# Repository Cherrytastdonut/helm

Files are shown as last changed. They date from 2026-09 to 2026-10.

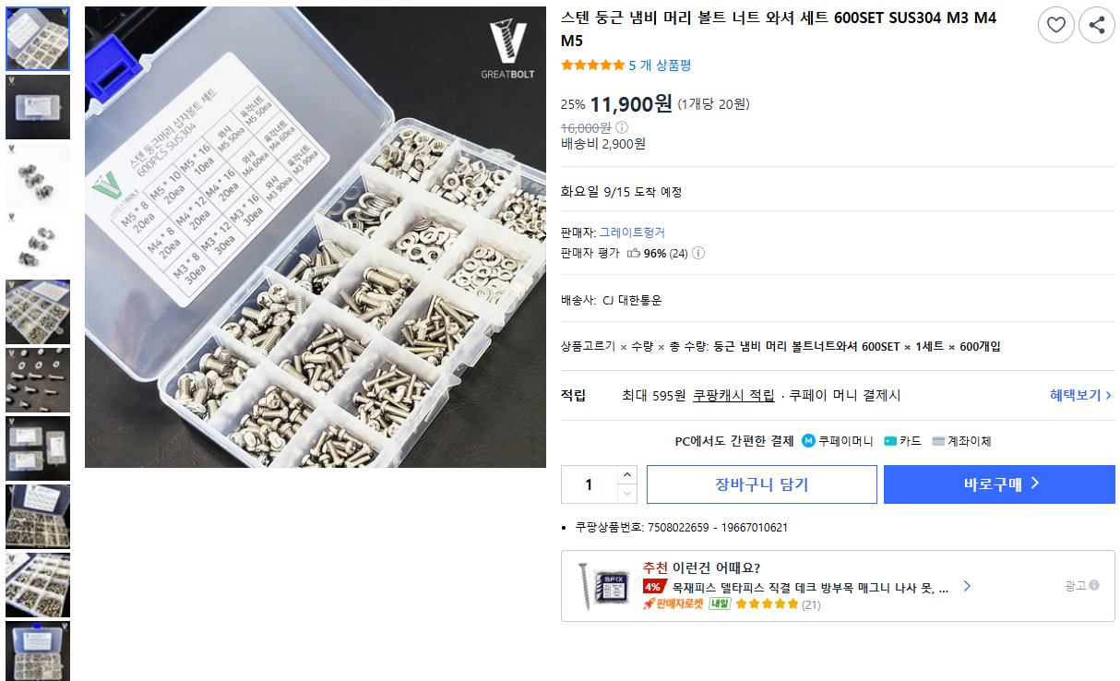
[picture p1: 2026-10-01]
assets/purchase-evidence/fastener-kit.png

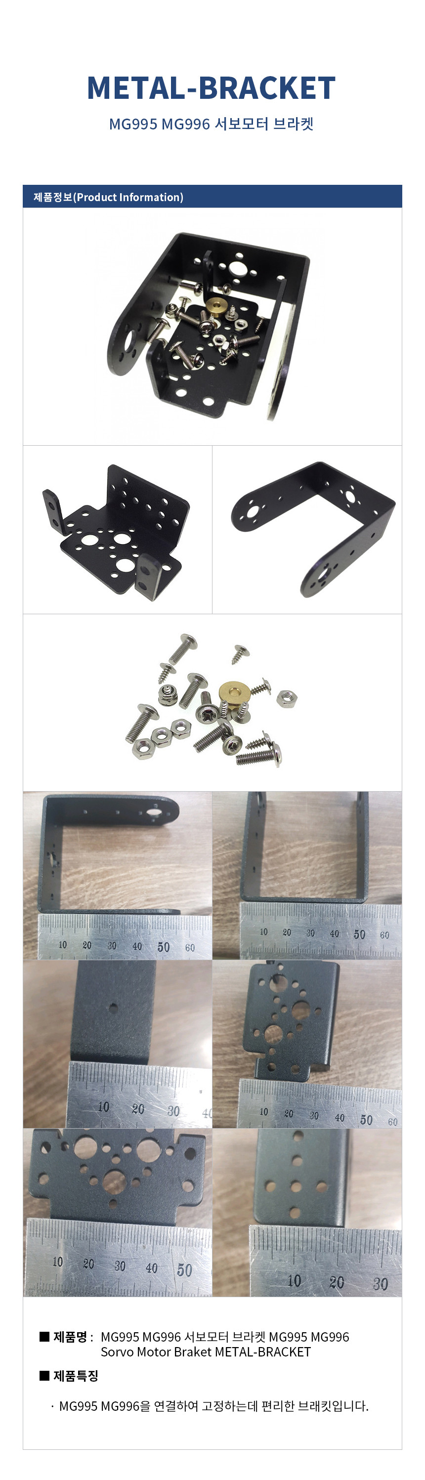
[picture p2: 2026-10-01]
assets/purchase-evidence/mg995-detail.jpg

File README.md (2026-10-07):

# HELM 자율점검 로봇

**최신: MEASURED_LAYOUT_20261006 · 3,888개 노드 · 재단·통전 승인 전 검토본입니다.** 구매 93개 항목, 치수표 13개 기록, CAD 노드를 연결하고 26개 형상에 치수와 배치를 반영했습니다.

1. [현재 상태](docs/00-status.md)와 [부품번호·실측 적용표](data/measurements-20261006/HELM_부품번호_실측적용표.xlsx).
2. [실측 반영·제작 가이드 6쪽](drawings/measurements-20261006/HELM_MEASURED_BUILD_GUIDE_KO.pdf).
3. [A3 1:1 윤곽 검토도 20쪽](drawings/measurements-20261006/HELM_CURRENT_FLAT_PROFILES_REVIEW_A3.pdf)와 [섀시 기준 4홀 대조 양식](drawings/measurements-20261006/HELM_CHASSIS_4HOLE_CHECK_A3.pdf).
4. [전체 CAD 백업 복원](docs/11-artifacts.md)과 [필수 확인·현장 조정](docs/15-needed-measurements.md).

| 자료 | 바로가기 |
|---|---|
| 모든 구매 항목 | [93개 번호 CSV](data/measurements-20261006/parts-numbered.csv) · [치수 원문과 적용](data/measurements-20261006/measurement-register.csv) |
| 최신 CAD·설계 범위 | [이번 반영 내용](docs/16-measured-layout.md) · [재생성 코드](cad/measurements-20261006/source/) |
| 제작 준비 | [재단](docs/04-fabrication.md) · [조립](docs/05-assembly.md) · [전기](docs/06-electrical.md) |
| 검사와 미확정 사항 | [검증 범위](docs/08-validation.md) · [겹침 24쌍·회전 10쌍](docs/10-open-items.md) |
| 기존 근거 | [상품 사진 대조](docs/14-product-photo-review.md) · [1차 구매](docs/parts/first-purchase.md) · [2차 구매](docs/parts/second-purchase.md) |
| 이전 작업 | [아카이브](archives/README.md) · [이력](docs/09-history.md) · [FlutterFlow 초안](docs/13-flutterflow-ai.md) |

보유 판재는 **5T 포맥스 600×900 mm 2장**입니다. 작은 칩 개별 측정은 필요하지 않으며, 고정 부품의 홀·배선·스페이서는 현장에서 조정합니다. 혼·기준 홀·큰 장착 홀·범퍼 기능은 먼저 확인해야 합니다. 2차 구매품을 모두 설치할 필요는 없습니다.

`LIB_SER0063.zip`은 모터 몸체 CAD입니다. 혼은 별도입니다. 형상 생략은 체결 완료나 간섭 해결을 뜻하지 않습니다. 과거 FINAL/PASS 또는 디자인·검색 불필요는 당시 확인한 본체와 검사 범위에 한정하며 최신 [상태 JSON](data/project-status.json)을 우선합니다.

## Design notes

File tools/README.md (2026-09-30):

# 자료 확인 도구

두 도구는 Python 3.9 이상과 표준 라이브러리만 사용합니다. 저장소 루트에서 실행합니다.

```bash
python tools/check_repository.py
python tools/restore_archives.py --all --verify-only
python tools/restore_archives.py --all --extract
```

첫 명령은 문서 링크·파일 수·상태 범위·파일 해시 목록을 검사합니다. 두 번째는 출력 파일을 만들지 않고 ZIP 조각과 전체 원본의 SHA-256을 검사합니다. 마지막은 검사가 끝난 ZIP을 downloads에 복원하고 각 원본별 빈 폴더에 풉니다.

의도한 문서 변경 후 `python tools/check_repository.py --write-catalog`로 파일 목록을 갱신하고 변경 내용을 검토하세요. 이 검사는 CAD 간섭 검증이나 실물 제작 승인이 아닙니다.

[원본 복원 안내](../docs/11-artifacts.md) · [CAD 생성 코드와 실행 이력](../docs/12-reproduce.md)

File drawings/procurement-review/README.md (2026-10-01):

# 현재 검토용 도면

[변경 안내 6쪽](HELM_PROCUREMENT_CHANGE_GUIDE_KO.pdf) · [A3 윤곽 20쪽](HELM_CURRENT_FLAT_PROFILES_REVIEW_A3.pdf)

A3 윤곽은 1:1 종이 대조용입니다. 실제 크기 100%로 인쇄하고 100 mm 기준선을 확인합니다. 최종 재단 승인본이 아닙니다. 1.6 mm 분배기판은 포맥스 대상이 아니며 깊이 형상은 STEP으로 확인합니다. [페이지 출처](../../data/procurement-review/DRAWING_INDEX.json).

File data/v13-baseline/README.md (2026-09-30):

# 자료 안내

과거 BOM·체결·배선·홀·목차입니다. 현재 구매 재고나 최신 배선 확정표가 아닙니다.

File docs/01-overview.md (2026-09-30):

# 전체 구성

기존 도면에서 HELM은 Autonomous Inspection Robot으로 정의된 궤도형 점검 로봇입니다. 아래는 확보된 기구·구매 구성이며 실제 운용 성능 검증 결과가 아닙니다.

| 계통 | 주요 장치 | 역할 |
|---|---|---|
| 이동 | Hiwonder 궤도 섀시·엔코더 모터, MDD10A | 주행 구동 |
| 연산 | Jetson Orin Nano Super 8GB, SSD, AX210 | 연산·저장·통신 |
| 제어 | ESP32 DevKit 38핀 | 저수준 인터페이스 후보, 펌웨어 미확보 |
| 감지 | C920, MLX90640 계열, RPLIDAR A2M12, BNO085 | 영상·열·거리·자세 |
| 카메라 구동 | SER0063 ×2 | 팬·틸트, 혼 미확정 |
| 전원/보호 | AGM 12V 7Ah, 변환기, 배전·퓨즈·릴레이·E-STOP | 실제 결선/정격 확인 필요 |
| 접촉/출력 | 4개 리미트 스위치, USB 스피커 | 범퍼 감지·경보 구성 |

```mermaid
flowchart TD
    A[영상·거리·열 입력] --> B[Jetson 연산부]
    B --> C[ESP32 제어부]
    D[엔코더·범퍼·자세 입력] --> C
    C --> E[주행 드라이버]
    C --> F[카메라 서보]
    B --> G[로그·상태·경보]
```

기능 관계도입니다. 확정 배선도나 GPIO 핀맵으로 사용하지 않습니다. 기구는 하부 프레임, 배터리/전원부, 상부 데크, 제어부, LiDAR 타워, 카메라, 범퍼로 구성됩니다.

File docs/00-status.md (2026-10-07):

# 현재 상태

**MEASURED_LAYOUT_20261006 / 3,888개 노드 / 재단·통전 승인 전**입니다.

| 항목 | 현재 내용 |
|---|---|
| 부품 매핑 | 1차 29 + 2차 64 = 93행, CAD 노드 3,888개 연결 |
| 치수 기록 | 13개 중 실측·근사 실측 10개. 상품명·카탈로그 표기를 별도 분류 |
| 형상 변경 | 꺽쇠 16개, C920 7개, 패드·측판·로커 = 26개 |
| 제외한 형상 | 미구매 ADC 몸체 27개, 구형 꺽쇠 체결 형상 160개, 스트랩 2개, 배선 1개 |
| 유지한 몸체 | CP003·배터리·승압기·퓨즈박스·SER0063·C715·열화상 |
| 산출물 | 제작 후보 STEP 128개, DXF 20개, 가이드 6쪽, A3 윤곽 20쪽, 섀시 4홀 확인지 |

변경부 후보 80쌍 중 겹침 24쌍(C920 내부 참조 4쌍 포함), 카메라 9개 자세 검사에서 고유 10쌍을 기록했습니다. 체결품 생략은 간섭 해결이나 체결 완료가 아닙니다. 팬 ±45°·틸트 ±20°는 검사 자세이며 승인 동작 범위가 아닙니다.

[필수 확인](15-needed-measurements.md)은 혼·비상정지·섀시 기준 홀·범퍼입니다. 고정 꺽쇠·CP003 홀은 실물 전사, 스페이서·배선은 현장 조정합니다. 모터 본체나 작은 칩을 다시 전부 재지 않습니다. MG995 프레임은 회전축·하중 부품으로 채택할 때만 내측·홀·두께가 필요합니다.

[부품번호·실측 적용표](../data/measurements-20261006/HELM_부품번호_실측적용표.xlsx) · [CAD 복원](11-artifacts.md) · [검사 상세](08-validation.md)

최신 같은 리비전의 CAD·치수표·검증이 우선입니다. 과거 FINAL/PASS나 디자인·검색 불필요는 당시 확인한 본체와 범위에 한정합니다.

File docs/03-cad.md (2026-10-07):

# CAD·설계도 읽는 법

현재 **MEASURED_LAYOUT_20261006**은 3,888개 노드의 실측 반영 검토본입니다. [상세 변경](16-measured-layout.md)과 [현재 CAD 복원](11-artifacts.md)을 먼저 확인해 주세요.

| 파일 | 사용 범위 |
|---|---|
| 전체 STEP | 전체 조립체 배치. mm 단위 |
| EDITABLE/HELM_WORK | 현재 BREP 3,888개와 관계 메타데이터. 원 제조사 전체 피처 이력은 아님 |
| 제작 STEP 128개 | 전체 좌표를 유지한 3D 홈·깊이. 모두 포맥스 재단품은 아님 |
| 변경 STEP 26개 | 꺽쇠·카메라·패드·측판·로커. 제작 후보와 일부 중복 |
| 선택 재고 STEP 3개 | 부스바·MG995 두 프레임의 외접 상자. 미설치, 상세 제조 CAD 아님 |
| DXF 20개 | 일정 두께 관통 윤곽. 19개 5T + 1개 1.6T 분배기판 참조 |
| A3 윤곽 20쪽 | 실제 크기 100%, 페이지 맞춤 해제 후 100 mm 선 확인 |
| 섀시 4홀 확인지 | 실물에 대조하는 중심점. 본판 재단 도면 아님 |

꺽쇠의 실제 홀·두께·리브, C920 힌지 상대 자세, 로커 내부 깊이 분할, 혼 연결부는 미확정입니다. 고정 부품 홀은 실물을 놓고 전사합니다. 깊이가 다른 형상을 평판으로 납작하게 가공하지 않습니다.

과거 V13(4,102개), SER0063(4,152개), PROCUREMENT(4,078개) 파일은 이력입니다. 현재 파일을 덮어쓰거나 과거 변경 스크립트를 반복 적용하지 않습니다.

[현재 변경 기록](../data/measurements-20261006/REVISION.json) · [STEP·DXF 인덱스](../data/measurements-20261006/FABRICATION_INDEX.json)

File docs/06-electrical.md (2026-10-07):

> 현재 치수 반영 CAD는 MEASURED_LAYOUT_20261006입니다. 이 문서의 전기 검토는 배선 실물 시험 완료를 뜻하지 않습니다. CAD의 무효 경로는 [현재 기록](../data/measurements-20261006/wires.json)을 따릅니다.

# 배선·전원 준비

CAD의 배선 의도와 미해결 항목입니다. 완성된 결선도나 확정 핀맵이 아닙니다.

12V AGM 배터리, 메인 퓨즈/스위치, 분기 보호·배전, 모터 차단 릴레이/E-STOP, 연산용 승압부, 5V 보조 전원부가 구매·CAD 자료에 있습니다. 실제 연결·정격은 부품 자료와 실측으로 확인합니다.

| 항목 | 현재 문제 | 완료 조건 |
|---|---|---|
| SER0063 2개 | 구형 4.8V 메모 사용 불가 | 제조사 5-8.4V 범위, 공급 전압·공유 부하·동시 전류 확인 |
| 서보 2개 배선 | 이전 경로 제거 | 실제 리드선 출구·극성·신호 리턴·움직임 루프 |
| C920 USB | 높이 변경 뒤 경로 제거 | 팬/틸트 움직임·굽힘·고정·플러그 접근 |
| RPLIDAR | 기존 배선표에 경로 없음 | 실제 케이블·Jetson 인터페이스·스캔 영역 밖 경로 |
| ADS1115 | 구매 목록에 없어 받침·체결품·가짜 연결 제거 | 보유 부품 기준 전압 취득 회로 확정 |
| 전압 분압 입력 | 보조 퓨즈 요구가 형상에 직렬 반영되지 않음 | 보유 보호부품·정격·연결 반영 |
| 배전 | CP003 외곽 적용, 기존 BUS 포트 좌표/경로 무효 | 단자 방향·정격·기구 위치·분기 식별 |
| 릴레이/E-STOP/퓨즈 | 실물 동작 미검증 | 접점·코일·억제소자 방향·선재·정격·차단 확인 |
| 커넥터 | 외형·접근 방향 참조 | 실제 키·공동·엔코더/모터 핀·극성 확인 |

SER0063 제조사 출처: https://www.dfrobot.com/product-2787.html (2026-09-30 확인). CAD 모양으로 핀 번호를 추정하지 않습니다.

[wires.json](../data/procurement-review/wires.json)의 앞선 SER0063 수정에 따른 세 경로는 NOT_RELEASED_SER0063_REPLACEMENT입니다. [ports.json](../data/procurement-review/ports.json)의 새 서보 리드선은 UNMEASURED_LEAD_EXIT입니다. 다른 기존 경로도 전체 실물 검증을 새로 완료한 것이 아닙니다.

과거 [배선표](../data/v13-baseline/WIRING_TABLE.csv)와 PDF 183쪽 E-211은 문제 추적용입니다. 단자 식별 → 전원 분리 상태 배선/단락 확인 → 부하 연결 전 출력 전압/극성 확인 → 회로별 단계 확인 → 차단/비상정지 → 가동부 케이블 확인을 기록합니다.

## 구매품 반영에 따른 현재 배선 상태

이번 리비전에서 배전 15개, 열화상 1개, ADC/전압취득 2개, 총 18개 경로를 무효 처리했습니다. geometry_valid=false, points=[], 길이 미확정이며 앞선 서보 2개·C920 경로 보류도 유지합니다. [이전 경로 기록](../data/procurement-review/SUPERSEDED_ROUTES.json).

열화상은 PH2.0 4핀입니다. GND/VCC/SDA/SCL 기능은 확인했지만 실제 결합 방향·핀 순서와 케이블 출구를 대조해야 합니다. 잘못된 2.54 mm 결합 플러그를 제거했습니다.

CP003 입력 2/출력 8에 예전 14개 논리 접속점을 임의 배정하거나 한 단자에 복수 전선을 넣지 않습니다. 내부 극 그룹과 필요한 분기 수부터 확인합니다. 판매 페이지 정격 표기도 서로 달라 전기 정격을 확정하지 않았습니다. 1차 부스바를 함께 사용하려면 그 규격과 내부 연결부터 확인합니다.

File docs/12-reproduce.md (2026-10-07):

# CAD·도면 도출과 재현

[기준본 + 델타](11-artifacts.md)를 복원한 뒤 현재 BREP를 사용합니다. 수정 스크립트를 이미 수정된 입력에 반복 적용하지 않습니다.

저장소 루트에서 CadQuery/OCP·ezdxf·ReportLab이 설치된 Python으로 실행합니다.

```bash
python cad/measurements-20261006/source/export_compact_snapshot.py --work downloads/measured/EDITABLE/HELM_WORK --step downloads/measured/CAD/HELM_MEASURED_COMPACT.step
python cad/measurements-20261006/source/export_current_parts.py --output downloads/measured
python cad/measurements-20261006/source/export_changed_parts.py --output downloads/measured
python cad/measurements-20261006/source/validate_full_step.py --output downloads/measured --step downloads/measured/CAD/HELM_MEASURED_COMPACT.step
python cad/measurements-20261006/source/validate_measurements.py --output downloads/measured
python cad/measurements-20261006/source/make_profiles.py --output downloads/measured --font /path/to/Korean-Regular.ttf
python cad/measurements-20261006/source/make_guide.py --output downloads/measured --font /path/to/Korean-Regular.ttf
python cad/measurements-20261006/source/make_chassis_check.py --output downloads/measured --font /path/to/Korean-Regular.ttf
```

폰트 경로는 실제 한국어 TTF로 바꾸고 전체 STEP은 빈 새 파일명으로 내보냅니다. compact 방식은 중복 2D 곡선 표현을 생략하며 3D 축척을 줄이지 않습니다.

BREP → 기준면·두께 확인 → 제작 STEP → 일정 두께 관통 윤곽 DXF → 보류 범위를 표시한 PDF → 재읽기·시각 검수 → 같은 리비전 ZIP 순서입니다. 깊이 형상을 평판으로 납작하게 만들지 않습니다.

`build_measured_cad.py`는 수정 전 PROCUREMENT_REVIEW 입력에서 변경을 처음 적용한 이력 코드입니다. 현재 재출력은 위 방식으로 충분합니다. 부품표 생성 소스는 `make_workbook.mjs`이며, 제공된 Excel을 그대로 사용하셔도 됩니다.

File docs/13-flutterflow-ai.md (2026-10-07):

# FlutterFlow AI에 전달할 요구사항

과거 사용자 요청을 이어가기 위한 **새 화면 요구사항 초안**입니다. 기존 앱이나 서버가 구현되었다는 의미가 아닙니다. 아래 블록을 복사해 사용할 수 있습니다. 먼저 [현재 상태](00-status.md)와 [소프트웨어 현황](07-software.md)을 함께 제공합니다.

```text
HELM 로봇의 제작 준비와 점검 기록을 확인하는 한국어 앱 화면을 설계해 주세요.

프로젝트의 확인된 상태:
- 현재 CAD는 MEASURED_LAYOUT_20261006, 3,888개 노드의 구매품 반영 검토본이며 제조 승인본이 아닙니다.
- C715 2280·CP003 외곽·전원판을 반영했고 미구매 ADC 받침을 제거했습니다. 실측을 26개 형상에 반영했고 카메라 자세 검사에는 고유 10쌍이 남습니다. 형상 생략은 간섭 해결이 아닙니다.
- 1차 구매는 이전 CSV의 29품목, 2차 구매는 새 XLSX 2주차의 64행입니다.
- 보유 부품만 사용합니다. 2차 품목 전부 장착은 요구사항이 아닙니다.
- 판재는 5T 포맥스 600×900 mm 2장입니다. 합판으로 표시하지 마세요.
- 필수 확인은 실제 혼, 비상정지 5T 장착, 섀시 기준 4홀·적층, 범퍼 작동·복귀입니다. 고정 부품 홀·배선·스페이서는 현장 조정하며 작은 칩 개별 측정은 불필요합니다.
- 주행 펌웨어·서버 API·실시간 통신 사양은 아직 확보되지 않았습니다.

만들 화면:
1. 홈: 현재 리비전, 제작 승인 여부, 남은 작업, CAD 미리보기, 도면 바로가기.
2. 보유 부품: 1차/2차, 원본 행 번호, 모델, 수량, 적용 여부, 실측 여부, 근거 링크.
3. CAD·도면: 최신 구매품 반영본과 과거 V13/SER0063 검토본을 구분해 PDF/STEP/DXF/ZIP 안내 표시.
4. 제작 준비: 실측→CAD 수정→간섭·배선 검증→재단도 확정→가조립 순서와 확인 기록.
5. 미해결 항목: 혼·브래킷, 기존 체결부 간섭, 실제 부품 대조, 전원·배선.
6. 조립·시험 기록: 날짜, 리비전, 측정값, 사진, 결과, 후속 조치.

표시 규칙:
- 확정, 공칭, 추정, 미확정, 미실시를 구분하세요.
- 검사한 팬 ±45°/틸트 ±20°를 승인된 동작 범위로 표시하지 마세요.
- 미측정 값을 0, 정상, 완료로 바꾸지 마세요. 비어 있는 상태를 지원하세요.
- 실제 통신 연결 전에는 모든 예시 데이터를 '데모'로 표시하세요.
- 하드웨어 동작 버튼이나 실시간 상태를 실제 작동하는 기능처럼 만들지 마세요.
- 앱 화면의 정지 표시는 하드웨어 E-STOP을 대신하지 않습니다.
- 실제 API, 로그인, 저장소, 다운로드 주소는 연결 사양 확정 후 적용하세요.
- 비공개 GitHub/Drive 토큰을 클라이언트 코드나 화면에 넣지 마세요.

참고할 저장소 자료:
README.md
data/project-status.json
data/purchases/source-rows.json
docs/00-status.md
docs/02-parts.md
docs/10-open-items.md
docs/11-artifacts.md
docs/14-product-photo-review.md
docs/15-needed-measurements.md
records/hardware-measurements-template.md
records/build-and-commissioning-template.md

먼저 화면 구조와 데이터 필드를 제안하고, 확정되지 않은 부분을 목록으로 남겨 주세요.
```

비공개 저장소 파일을 앱에서 배포하는 인증 방식은 아직 정하지 않았습니다. 위 파일들은 설계 참고 입력이며 앱용으로 확정된 API 계약이 아닙니다.

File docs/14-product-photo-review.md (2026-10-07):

> 상품 사진 대조의 기존 근거는 유지합니다. 최신 실측 기록과 확인 우선순위는 [실측 반영 내용](16-measured-layout.md), [필수 확인·현장 조정](15-needed-measurements.md)을 따릅니다.

# 구매품 사진·제조사 자료 대조

확인일 2026-10-01 / 적용 리비전 PROCUREMENT_REVIEW_20261001.

구매 링크, 제공된 XLSX의 구매측 판매 페이지 캡처, 제조사 치수·3D 파일을 함께 대조했습니다. 상품 사진·선택 옵션은 배송된 개체의 실측 기록과 구분합니다. 비교견적의 다른 판매자 제품을 추가 재고로 합산하지 않습니다.

| 구매 부품 | 확인한 근거 | CAD 처리 | 남은 범위 |
|---|---|---|---|
| C715, 2차 83행 | 512GB 선택·K512GM2SP0-C7T, 명목 80×22×2.5 mm | 2242 참조 6개·선택형 2230 SSD/나사 제거, 실제 2280 슬롯 배치 | PCB·키·칩은 명목 형상, 고정나사·실물 끼움 |
| CP003, 79행 | 녹색 몸체·투명 덮개, 100×45×33 mm, 입력 2/출력 8 | 실제 외곽 크기 공간 모델 적용, 전원판의 옛 홀·하단 간섭 수정 | 고정홀·덮개 개방·전선 출구·내부 연결 |
| 열화상 220565, 25행 | SEENGREAT MLX90640-D55, 제조사 STEP | 기존 215개 형상 경계·부피 대조 후 유지, PH2.0 정보 정정 | 결합 플러그 방향·케이블 |
| SER0063, 30행 | 첨부 모터 STEP, 25T/5.9 mm 축·혼 동봉 | 모터 2개 교체 유지, 축척 변경 없음 | 사용할 혼의 홀·두께·장착 높이 |
| MG995/MG996 브래킷, 78행 | 금속 프레임과 체결품·자 대조 사진 | 치수 없이 호환 브래킷을 만들어 넣지 않음 | 안쪽 폭·홀·두께·축 지지부 |
| NEXT-505UHP, 42행 | 흰 몸체·4포트·일체형 케이블, 101×41×25 mm | 기존 모델명·외형 유지 | USB/DC 포트·배선 치수 |
| 네이쳐툴 소형/중형, 54-55행 | 소형 각 면 2홀, 중형 각 면 3홀·보강 돌기 | 기존 가정을 실측 완료로 승격하지 않음 | 다리 길이·폭·두께·홀·돌기 |
| 혼합 볼트 세트, 53행 | M3/M4/M5 볼트·일반 너트·와셔 라벨 | 일반 M4 너트 존재 확인, 실제 길이별 수량은 별도 | 머리·너트·와셔 높이와 재고 |
| M4 나일론 너트, 75행 | M4 선택과 나일론 링 | 일반 너트 3.2 mm와 같은 높이로 가정하지 않음 | 높이·유효 체결 길이 |
| BNS-30, 39행 | 제조사 탭핑 나사·케이블 홀더 구성 | M2/M2.5 기계나사·너트 보유 증거로 쓰지 않음 | 실제 소형 기계나사 재고 |
| Bosch 2607010529, 60행 | 2/3/4/5/6/8 mm 구성 | D4.5 도면과 공구 차이를 보류 표시 | 설계·가공법 함께 확정 |

SSD는 원본 NVIDIA `OFFICIAL_JETSON_0564_Solid` 소켓과 `OFFICIAL_JETSON_0705_Solid` 끝단 지지부 기준입니다. 42 mm 카드를 예전 위치에서 80 mm로 늘리기만 하면 받침판과 겹칩니다. 카드 진입부·키는 명목 결합 형상이며 정확한 공급사 PCB 제조 도면은 아닙니다.

CP003의 고정홀·단자 좌표를 사진 비율로 추정해 가공 치수로 쓰지 않았습니다. 입력 2/출력 8에 이전 14개 논리 접속점을 임의 배정하지 않습니다. 기존 부스바 좌표와 관련 경로는 무효 처리했습니다.

열화상 제조사 STEP은 215개 형상 모두 경계 오차 0.001 mm 미만·부피 차이 0.01 mm³ 미만으로 일치했습니다. `HAT-V1.2` 파일명만으로 다른 구매품으로 판정하지 않습니다. 기존 보드 커넥터 접점 피치는 2 mm이며, 잘못된 2.54 mm 결합 플러그 프록시와 포트 표기를 정리했습니다. 표시 색은 실물 도장색을 보증하지 않습니다.

## 보존한 사진

[캡처 셀·원본 미디어·해시](../data/purchases/product-evidence-20261001.json)

| 부품 | 사진 |
|---|---|
| SSD·단자대·열화상 | [C715](../assets/purchase-evidence/c715-512gb.png) · [CP003](../assets/purchase-evidence/szh-cp003.png) · [220565](../assets/purchase-evidence/seengreat-220565.png) |
| 모터·브래킷 | [SER0063](../assets/purchase-evidence/ser0063.png) · [브래킷](../assets/purchase-evidence/mg995-bracket.png) · [자 대조 상세](../assets/purchase-evidence/mg995-detail.jpg) |
| 허브·꺽쇠 | [NEXT](../assets/purchase-evidence/next-505uhp.png) · [소형](../assets/purchase-evidence/naturetool-small.png) · [중형](../assets/purchase-evidence/naturetool-medium.png) |
| 체결품 | [혼합 세트](../assets/purchase-evidence/fastener-kit.png) · [M4 나일론](../assets/purchase-evidence/m4-nyloc.png) · [스페이서](../assets/purchase-evidence/m3-spacers.png) · [BNS-30](../assets/purchase-evidence/bns30.png) |
| 공구 | [Bosch](../assets/purchase-evidence/bosch-drills.png) |

## 제조사·판매자 출처

- [KLEVV C715](https://www.klevv.com/ken/products_details/ssd/Klevv_Cras_C715.php)
- [NVIDIA 2280 슬롯](https://docs.nvidia.com/jetson/orin-nano-devkit/user-guide/latest/hardware_layout.html)
- [CP003 규격표](https://www.devicemart.co.kr/goods/view_contents?no=12498800&setMode=pc&zoom=1)
- [SEENGREAT 220565](https://seengreat.com/product/209/thermal-camera) · [STEP·핀 기능](https://seengreat.com/wiki/88/thermal-camera-mlx90640-d55)
- [DFRobot SER0063](https://www.dfrobot.com/product-2787.html)
- [MG995 브래킷](https://m.intopion.com/goods/view?no=3831971)
- [NEXT 제조사](https://www.ez-net.co.kr/sub/sub01_01_view.php?idx=1818&offset=1440) · [판매 규격](https://www.ssg.com/item/itemView.ssg?itemId=1000034199687)
- [ROBOTIS BNS-30](https://en.robotis.com/shop_en/item.php?it_id=903-0212-000)
- [Bosch 비트 구성](https://www.bosch-professional.com/in/en/pro-metal-hss-g-twist-drill-bit-set-3089834-ocs-ac/)

일부 링크의 접근 제한 때문에 제공된 원본 캡처를 함께 사용했습니다. 유사 상품 치수를 해당 구매품의 확정 치수로 옮기지 않습니다.

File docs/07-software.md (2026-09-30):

# 소프트웨어 현황

현재 확보된 실행 코드는 CAD 생성·도면 추출·렌더링·검증·패키징 도구입니다. 주행 펌웨어, 자율주행/점검 프로그램, 서버, FlutterFlow 앱 완성본은 제공 자료에서 확보되지 않았습니다.

다음은 개발 준비 목록이며 완료 이력이 아닙니다.

| 인터페이스 | 먼저 정할 것 |
|---|---|
| Jetson ↔ ESP32 | 연결 방식·메시지·주기·타임아웃·정지 동작 |
| 주행 | 실제 MDD10A 핀/레벨, 엔코더 단위·방향 |
| 센서 | 드라이버 버전·연결·좌표계·시간 기준 |
| 카메라 서보 | 중립·방향·기구 허용 범위·전원 조건 |
| 범퍼/E-STOP | 하드웨어 차단과 소프트웨어 감지 역할 |
| 로그/화면/경보 | 표시·저장·오류·통신 끊김 처리 |

실물 인터페이스 표 → 장치별 읽기·정지·오류 시험 → 저수준 통신 → 확인한 기능 통합 → 점검 시나리오/화면 확정 순서로 진행합니다. 근거 없이 ROS/JetPack 버전이나 GPIO 번호를 확정하지 않습니다.

실제 코드가 생기면 실행 방법·의존성·검사 결과를 이 문서와 함께 추가하세요. [CAD 코드 재현](12-reproduce.md)

이전 FlutterFlow AI용 요청을 이어갈 수 있도록 [복사용 화면 요구사항 초안](13-flutterflow-ai.md)을 추가했습니다. 새로 정리한 초안이며 구현 완료 기록은 아닙니다.

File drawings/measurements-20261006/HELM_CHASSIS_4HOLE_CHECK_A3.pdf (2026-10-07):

# HELM / 섀시 기준 4홀 대조

### A3 실제 크기 100% · 위에서 본 +X 오른쪽 / +Y 위쪽 · 좌우 반전 금지 · 종이 대조용, 재단 도면 아님

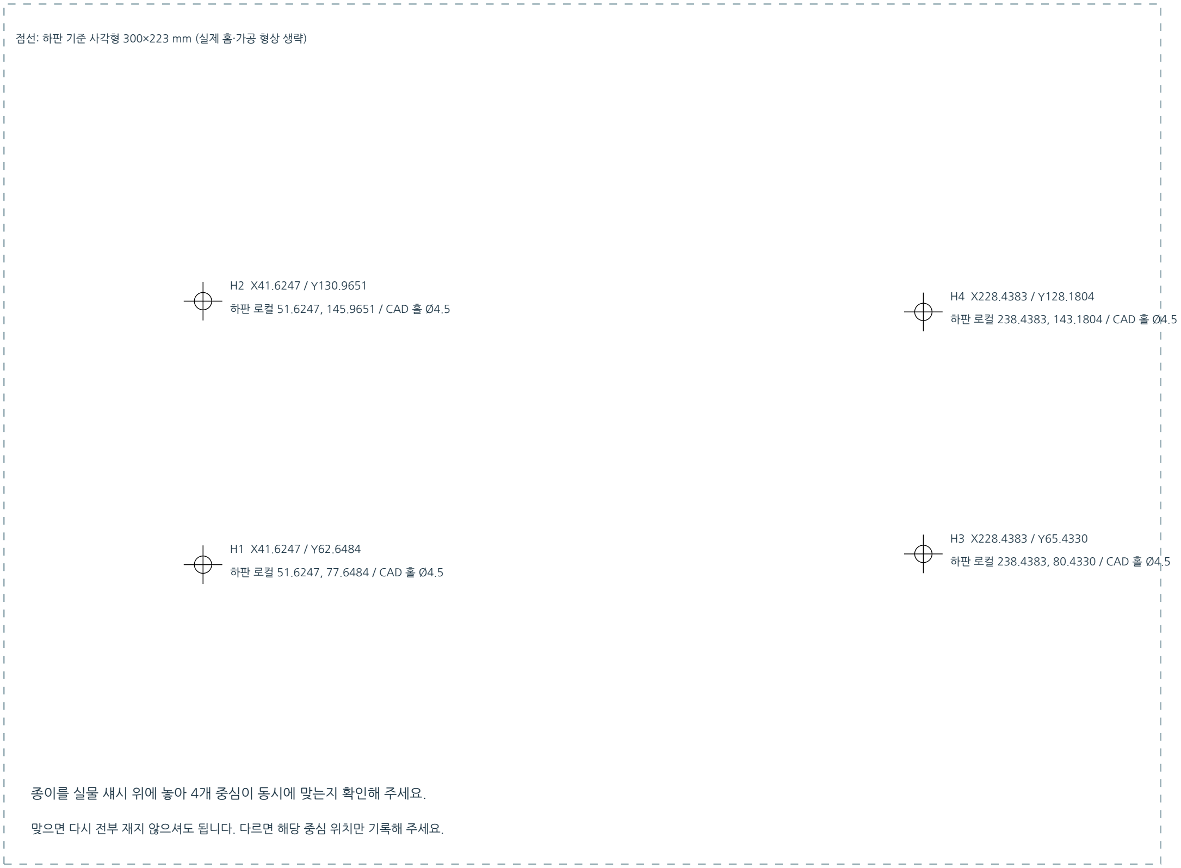
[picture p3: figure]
하판 로컬 51.6247, 77.6484 / CAD 홀 Ø4.5; 하판 로컬 51.6247, 145.9651 / CAD 홀 Ø4.5; 하판 로컬 238.4383, 80.4330 / CAD 홀 Ø4.5; 하판 로컬 238.4383, 143.1804 / CAD 홀 Ø4.5; 종이를 실물 섀시 위에 놓아 4개 중심이 동시에 맞는지 확인해 주세요.

점선: 하판 기준 사각형 300×223 mm (실제 홈·가공 형상 생략)

맞으면 다시 전부 재지 않으셔도 됩니다. 다르면 해당 중심 위치만 기록해 주세요.

기준선 100 mm

프린터 배율 확인 후 사용 · 5T 실물 두께·적층 높이는 별도 확인

MEASURED_LAYOUT_20261006

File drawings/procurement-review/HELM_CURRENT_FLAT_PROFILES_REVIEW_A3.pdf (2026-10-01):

## HELM / 현재 형상에서 추출한 평면 윤곽

# CUSTOM_BATTERY_PLATE

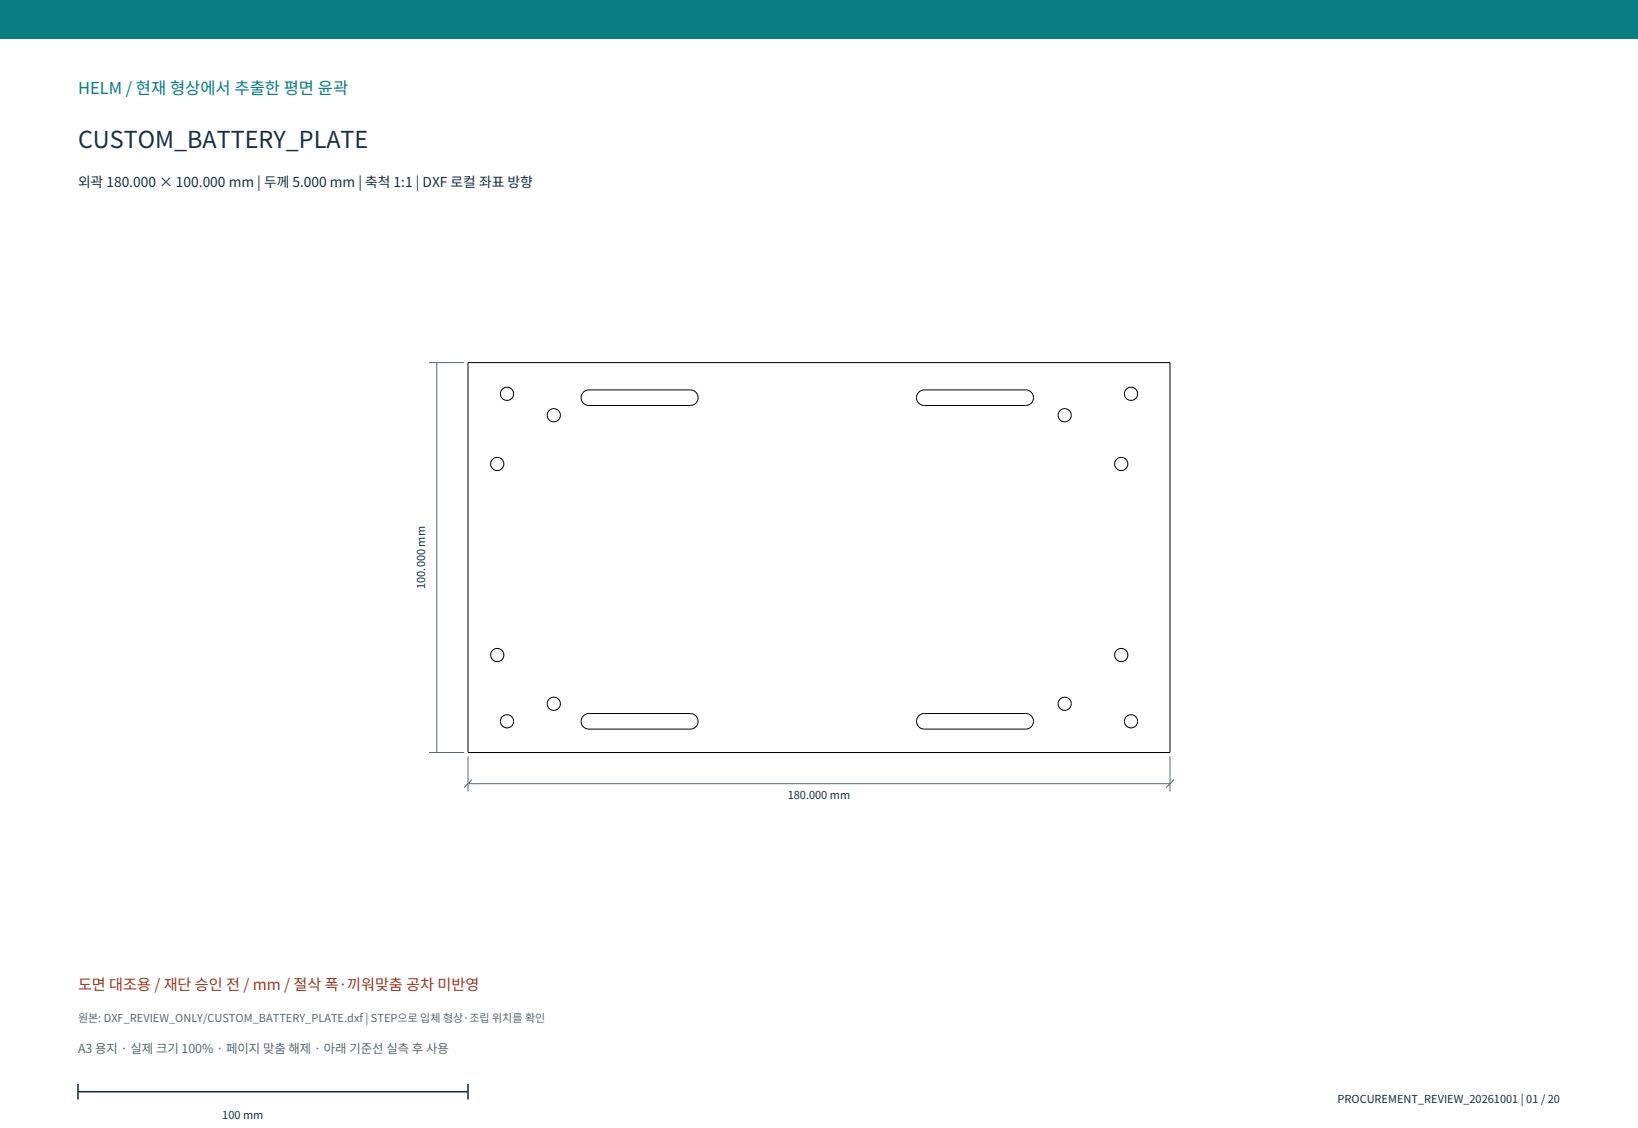
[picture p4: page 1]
PROCUREMENT_REVIEW_20261001 | 01 / 20

외곽 180.000 × 100.000 mm | 두께 5.000 mm | 축척 1:1 | DXF 로컬 좌표 방향

도면 대조용 / 재단 승인 전 / mm / 절삭 폭·끼워맞춤 공차 미반영

원본: DXF_REVIEW_ONLY/CUSTOM_BATTERY_PLATE.dxf | STEP으로 입체 형상·조립 위치를 확인

A3 용지 · 실제 크기 100% · 페이지 맞춤 해제 · 아래 기준선 실측 후 사용

# CUSTOM_CHASSIS_PAD_0_1

### 외곽 20.000 × 20.000 mm | 두께 5.000 mm | 축척 1:1 | DXF 로컬 좌표 방향

20.000 mm

20.000 mm

## 도면 대조용 / 재단 승인 전 / mm / 절삭 폭·끼워맞춤 공차 미반영

원본: DXF_REVIEW_ONLY/CUSTOM_CHASSIS_PAD_0_1.dxf | STEP으로 입체 형상·조립 위치를 확인

A3 용지 · 실제 크기 100% · 페이지 맞춤 해제 · 아래 기준선 실측 후 사용

# CUSTOM_CHASSIS_PAD_1_1

### 외곽 20.000 × 20.000 mm | 두께 5.000 mm | 축척 1:1 | DXF 로컬 좌표 방향

20.000 mm

20.000 mm

## 도면 대조용 / 재단 승인 전 / mm / 절삭 폭·끼워맞춤 공차 미반영

원본: DXF_REVIEW_ONLY/CUSTOM_CHASSIS_PAD_1_1.dxf | STEP으로 입체 형상·조립 위치를 확인

A3 용지 · 실제 크기 100% · 페이지 맞춤 해제 · 아래 기준선 실측 후 사용

# CUSTOM_CHASSIS_PAD_2_1

### 외곽 20.000 × 20.000 mm | 두께 5.000 mm | 축척 1:1 | DXF 로컬 좌표 방향

20.000 mm

20.000 mm

## 도면 대조용 / 재단 승인 전 / mm / 절삭 폭·끼워맞춤 공차 미반영

원본: DXF_REVIEW_ONLY/CUSTOM_CHASSIS_PAD_2_1.dxf | STEP으로 입체 형상·조립 위치를 확인

A3 용지 · 실제 크기 100% · 페이지 맞춤 해제 · 아래 기준선 실측 후 사용

# CUSTOM_CHASSIS_PAD_3_1

### 외곽 20.000 × 20.000 mm | 두께 5.000 mm | 축척 1:1 | DXF 로컬 좌표 방향

20.000 mm

20.000 mm

## 도면 대조용 / 재단 승인 전 / mm / 절삭 폭·끼워맞춤 공차 미반영

원본: DXF_REVIEW_ONLY/CUSTOM_CHASSIS_PAD_3_1.dxf | STEP으로 입체 형상·조립 위치를 확인

A3 용지 · 실제 크기 100% · 페이지 맞춤 해제 · 아래 기준선 실측 후 사용

# CUSTOM_FRONT_PANEL

### 외곽 218.000 × 120.000 mm | 두께 5.000 mm | 축척 1:1 | DXF 로컬 좌표 방향

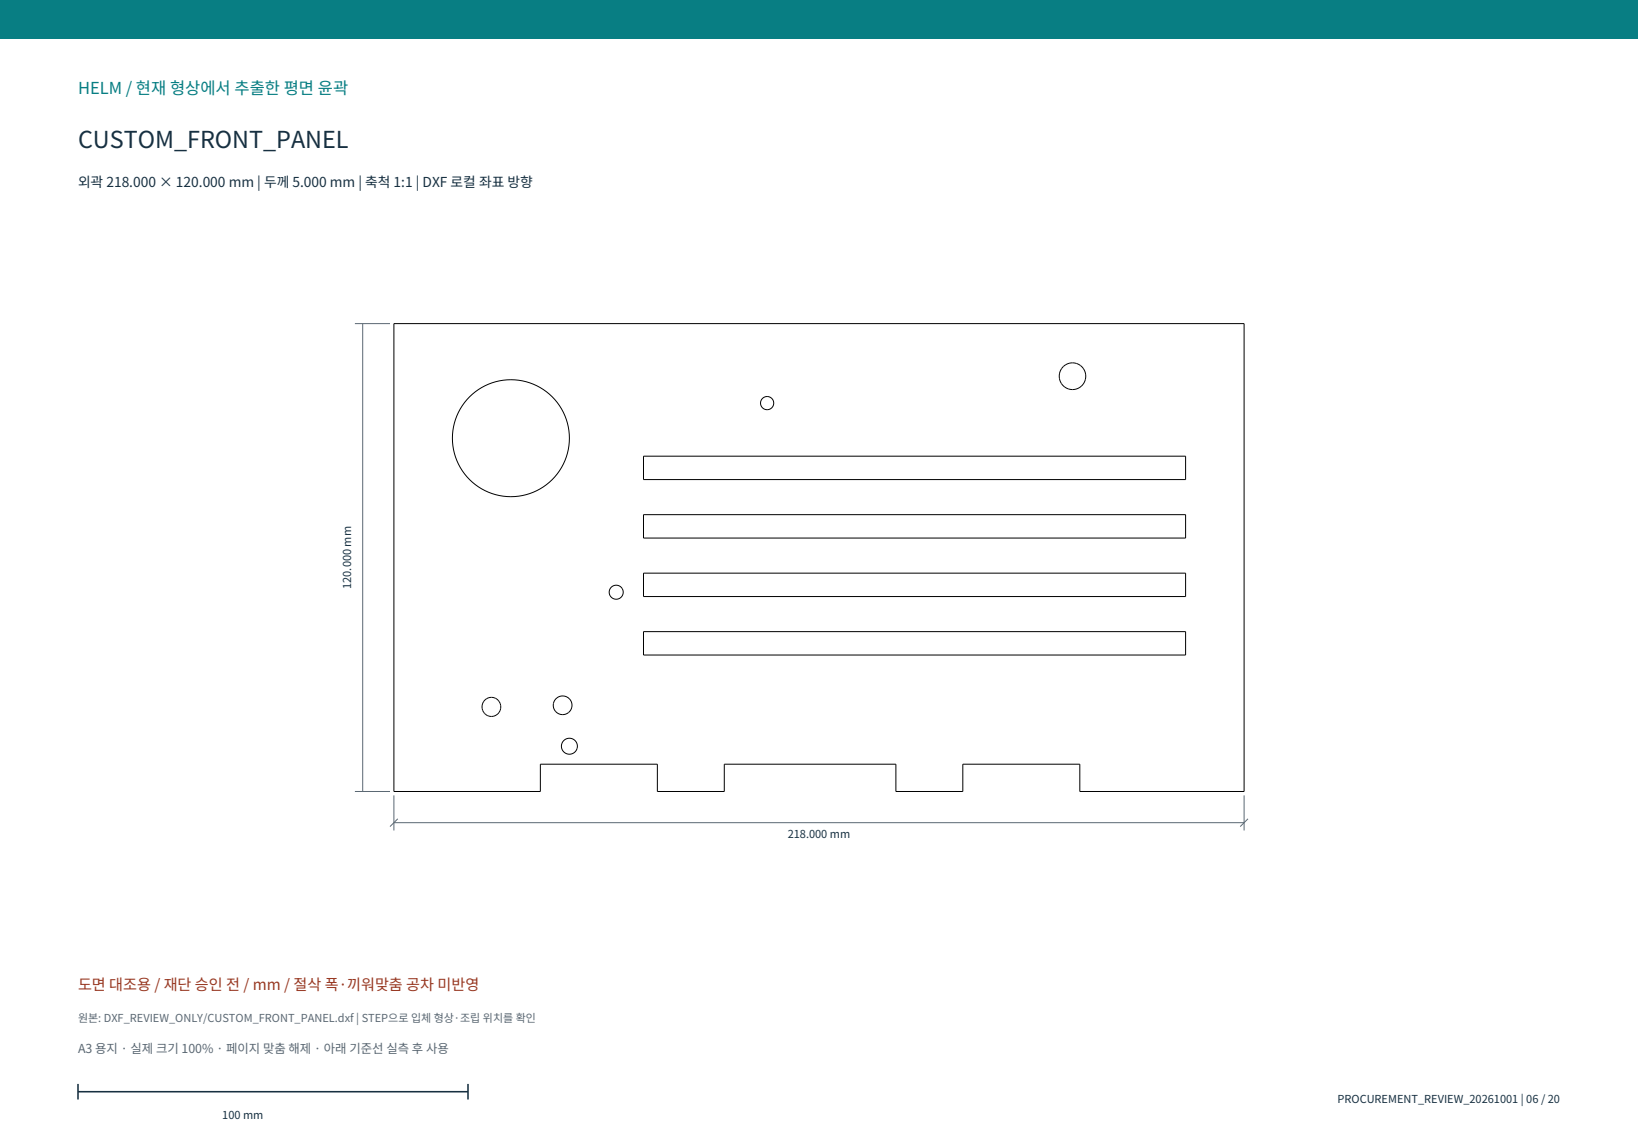
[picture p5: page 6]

도면 대조용 / 재단 승인 전 / mm / 절삭 폭·끼워맞춤 공차 미반영

원본: DXF_REVIEW_ONLY/CUSTOM_FRONT_PANEL.dxf | STEP으로 입체 형상·조립 위치를 확인

A3 용지 · 실제 크기 100% · 페이지 맞춤 해제 · 아래 기준선 실측 후 사용

# CUSTOM_LIDAR_BRIDGE

### 외곽 54.000 × 213.000 mm | 두께 5.000 mm | 축척 1:1 | 지면상 90도 회전

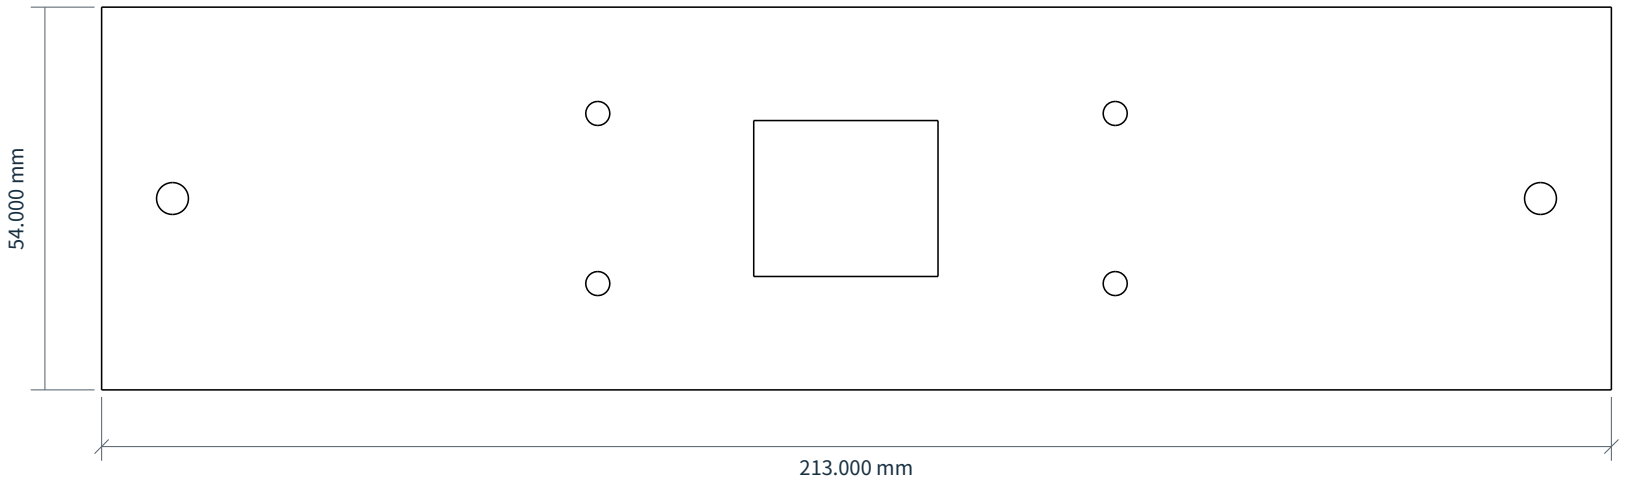
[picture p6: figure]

## 도면 대조용 / 재단 승인 전 / mm / 절삭 폭·끼워맞춤 공차 미반영

원본: DXF_REVIEW_ONLY/CUSTOM_LIDAR_BRIDGE.dxf | STEP으로 입체 형상·조립 위치를 확인

A3 용지 · 실제 크기 100% · 페이지 맞춤 해제 · 아래 기준선 실측 후 사용

# CUSTOM_LIDAR_PLATE

### 외곽 92.000 × 94.000 mm | 두께 5.000 mm | 축척 1:1 | DXF 로컬 좌표 방향

## 도면 대조용 / 재단 승인 전 / mm / 절삭 폭·끼워맞춤 공차 미반영

원본: DXF_REVIEW_ONLY/CUSTOM_LIDAR_PLATE.dxf | STEP으로 입체 형상·조립 위치를 확인

A3 용지 · 실제 크기 100% · 페이지 맞춤 해제 · 아래 기준선 실측 후 사용

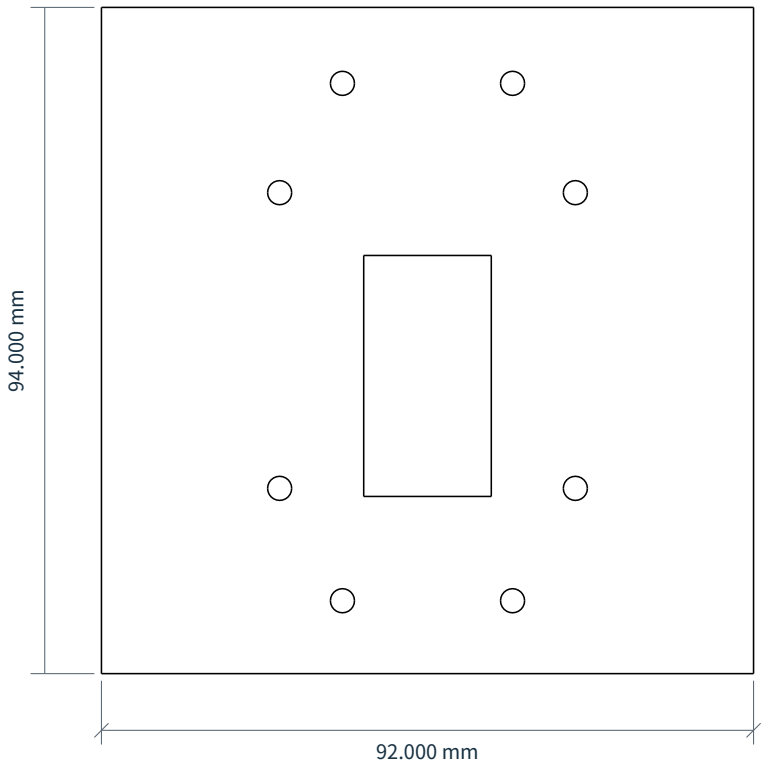
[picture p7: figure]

# CUSTOM_BATTERY_STOP_FRONT

### 외곽 5.000 × 73.000 mm | 두께 5.000 mm | 축척 1:1 | DXF 로컬 좌표 방향

5.000 mm

73.000 mm

## 도면 대조용 / 재단 승인 전 / mm / 절삭 폭·끼워맞춤 공차 미반영

원본: DXF_REVIEW_ONLY/CUSTOM_BATTERY_STOP_FRONT.dxf | STEP으로 입체 형상·조립 위치를 확인

A3 용지 · 실제 크기 100% · 페이지 맞춤 해제 · 아래 기준선 실측 후 사용

# CUSTOM_BATTERY_STOP_REAR

### 외곽 5.000 × 73.000 mm | 두께 5.000 mm | 축척 1:1 | DXF 로컬 좌표 방향

5.000 mm

73.000 mm

## 도면 대조용 / 재단 승인 전 / mm / 절삭 폭·끼워맞춤 공차 미반영

원본: DXF_REVIEW_ONLY/CUSTOM_BATTERY_STOP_REAR.dxf | STEP으로 입체 형상·조립 위치를 확인

A3 용지 · 실제 크기 100% · 페이지 맞춤 해제 · 아래 기준선 실측 후 사용

# CUSTOM_BATTERY_STOP_LEFT

### 외곽 155.000 × 5.000 mm | 두께 5.000 mm | 축척 1:1 | DXF 로컬 좌표 방향

155.000 mm

5.000 mm

## 도면 대조용 / 재단 승인 전 / mm / 절삭 폭·끼워맞춤 공차 미반영

원본: DXF_REVIEW_ONLY/CUSTOM_BATTERY_STOP_LEFT.dxf | STEP으로 입체 형상·조립 위치를 확인

A3 용지 · 실제 크기 100% · 페이지 맞춤 해제 · 아래 기준선 실측 후 사용

# CUSTOM_BATTERY_STOP_RIGHT

### 외곽 155.000 × 5.000 mm | 두께 5.000 mm | 축척 1:1 | DXF 로컬 좌표 방향

155.000 mm

5.000 mm

## 도면 대조용 / 재단 승인 전 / mm / 절삭 폭·끼워맞춤 공차 미반영

원본: DXF_REVIEW_ONLY/CUSTOM_BATTERY_STOP_RIGHT.dxf | STEP으로 입체 형상·조립 위치를 확인

A3 용지 · 실제 크기 100% · 페이지 맞춤 해제 · 아래 기준선 실측 후 사용

# CUSTOM_CAMERA_BASE

### 외곽 72.000 × 144.000 mm | 두께 5.000 mm | 축척 1:1 | DXF 로컬 좌표 방향

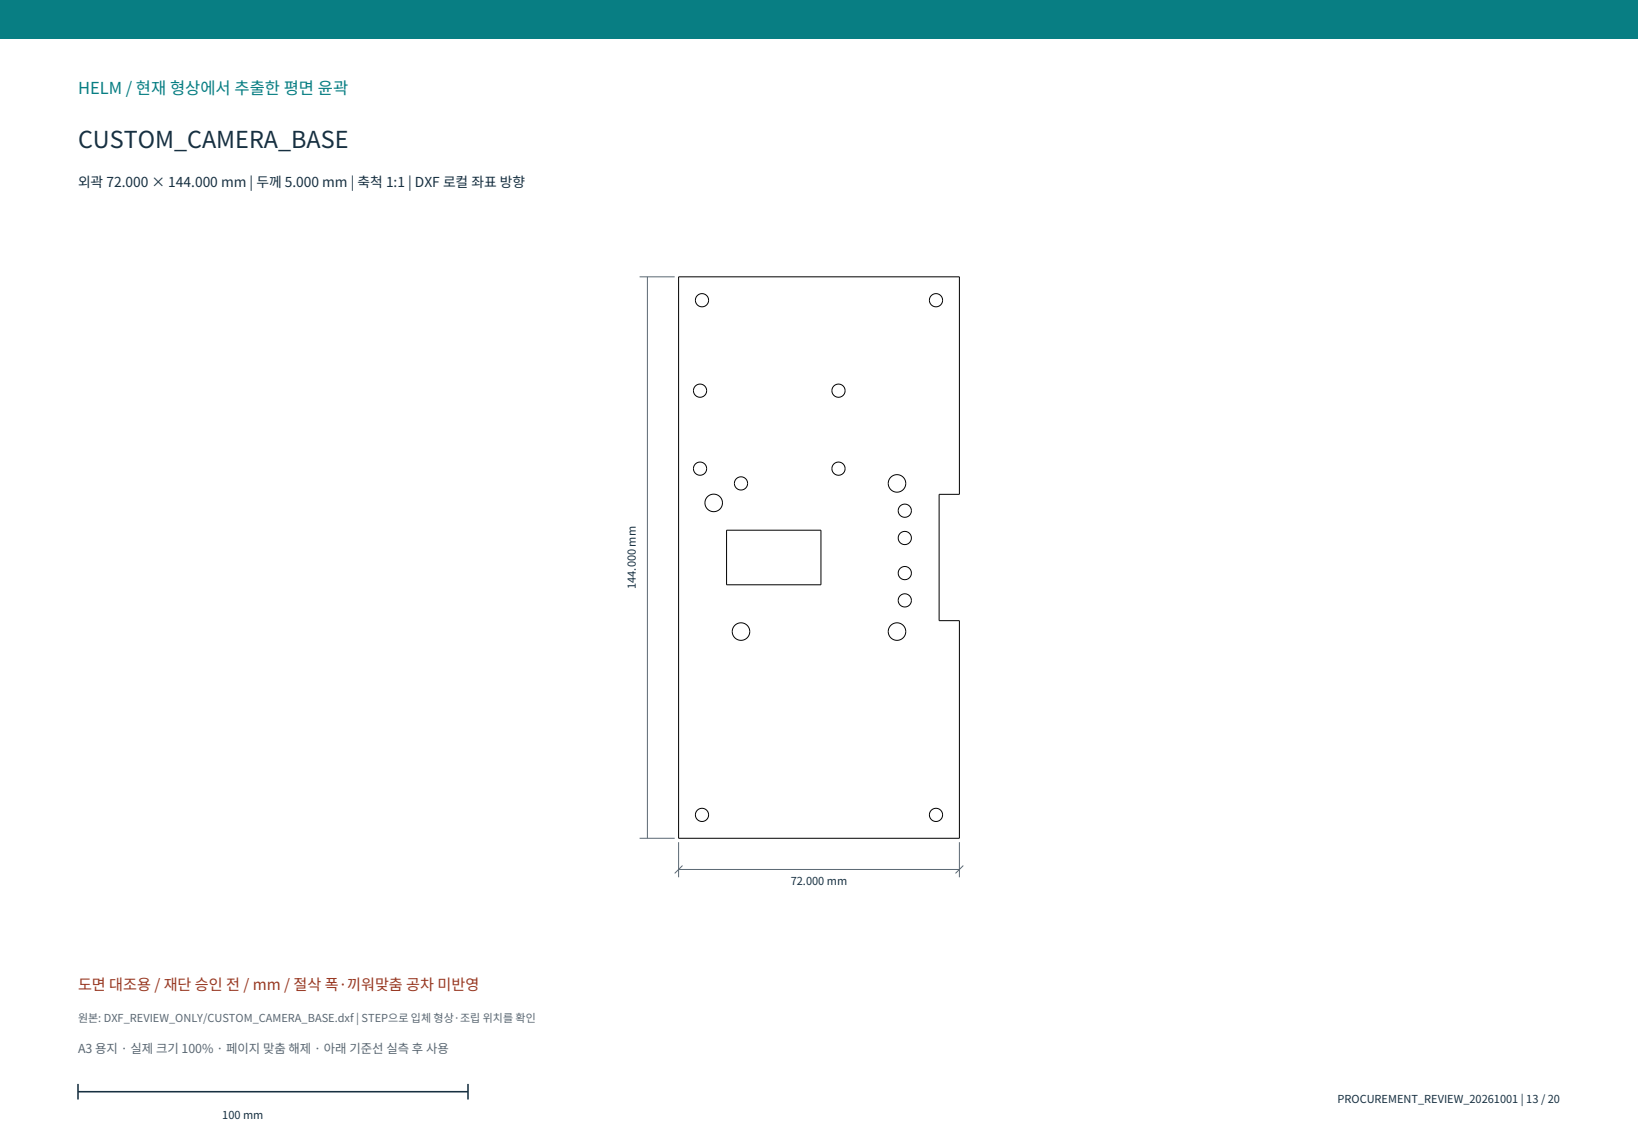
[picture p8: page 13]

도면 대조용 / 재단 승인 전 / mm / 절삭 폭·끼워맞춤 공차 미반영

원본: DXF_REVIEW_ONLY/CUSTOM_CAMERA_BASE.dxf | STEP으로 입체 형상·조립 위치를 확인

A3 용지 · 실제 크기 100% · 페이지 맞춤 해제 · 아래 기준선 실측 후 사용

# CUSTOM_PAN_ARM_LEFT

### 외곽 74.000 × 59.000 mm | 두께 5.000 mm | 축척 1:1 | DXF 로컬 좌표 방향

## 도면 대조용 / 재단 승인 전 / mm / 절삭 폭·끼워맞춤 공차 미반영

원본: DXF_REVIEW_ONLY/CUSTOM_PAN_ARM_LEFT.dxf | STEP으로 입체 형상·조립 위치를 확인

A3 용지 · 실제 크기 100% · 페이지 맞춤 해제 · 아래 기준선 실측 후 사용

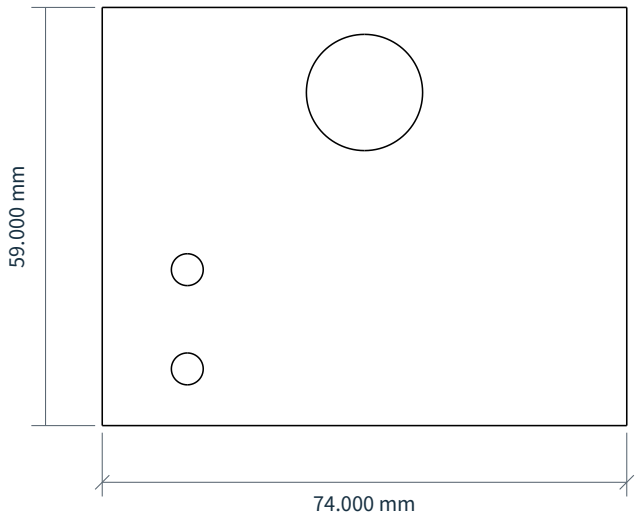
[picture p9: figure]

# CUSTOM_TILT_CHEEK_LEFT

### 외곽 70.000 × 50.000 mm | 두께 5.000 mm | 축척 1:1 | DXF 로컬 좌표 방향

70.000 mm

50.000 mm

## 도면 대조용 / 재단 승인 전 / mm / 절삭 폭·끼워맞춤 공차 미반영

원본: DXF_REVIEW_ONLY/CUSTOM_TILT_CHEEK_LEFT.dxf | STEP으로 입체 형상·조립 위치를 확인

A3 용지 · 실제 크기 100% · 페이지 맞춤 해제 · 아래 기준선 실측 후 사용

# CUSTOM_TILT_CHEEK_RIGHT

### 외곽 70.000 × 50.000 mm | 두께 5.000 mm | 축척 1:1 | DXF 로컬 좌표 방향

70.000 mm

50.000 mm

## 도면 대조용 / 재단 승인 전 / mm / 절삭 폭·끼워맞춤 공차 미반영

원본: DXF_REVIEW_ONLY/CUSTOM_TILT_CHEEK_RIGHT.dxf | STEP으로 입체 형상·조립 위치를 확인

A3 용지 · 실제 크기 100% · 페이지 맞춤 해제 · 아래 기준선 실측 후 사용

# CUSTOM_C920_SADDLE

### 외곽 70.000 × 104.800 mm | 두께 5.000 mm | 축척 1:1 | DXF 로컬 좌표 방향

## 도면 대조용 / 재단 승인 전 / mm / 절삭 폭·끼워맞춤 공차 미반영

원본: DXF_REVIEW_ONLY/CUSTOM_C920_SADDLE.dxf | STEP으로 입체 형상·조립 위치를 확인

A3 용지 · 실제 크기 100% · 페이지 맞춤 해제 · 아래 기준선 실측 후 사용

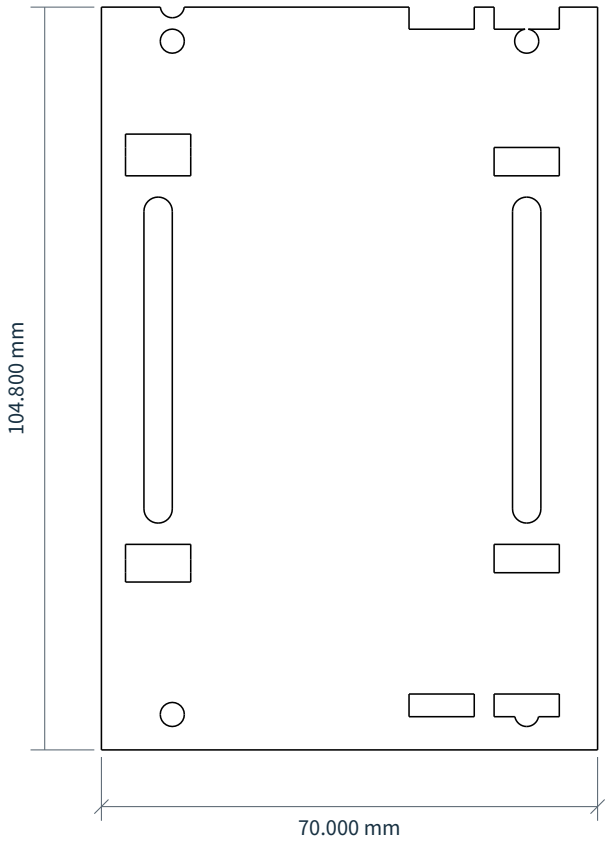
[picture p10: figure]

# CUSTOM_5V_DISTRIBUTOR

### 외곽 40.000 × 20.000 mm | 두께 1.600 mm | 축척 1:1 | DXF 로컬 좌표 방향

40.000 mm

20.000 mm

## 도면 대조용 / 재단 승인 전 / mm / 절삭 폭·끼워맞춤 공차 미반영

원본: DXF_REVIEW_ONLY/CUSTOM_5V_DISTRIBUTOR.dxf | STEP으로 입체 형상·조립 위치를 확인

주의: 1.6 mm 분배기판 형상 참조이며 포맥스 재단·회로 제작 승인 도면이 아닙니다.

# CUSTOM_PAN_SERVO_MOUNT

### 외곽 72.000 × 60.000 mm | 두께 5.000 mm | 축척 1:1 | DXF 로컬 좌표 방향

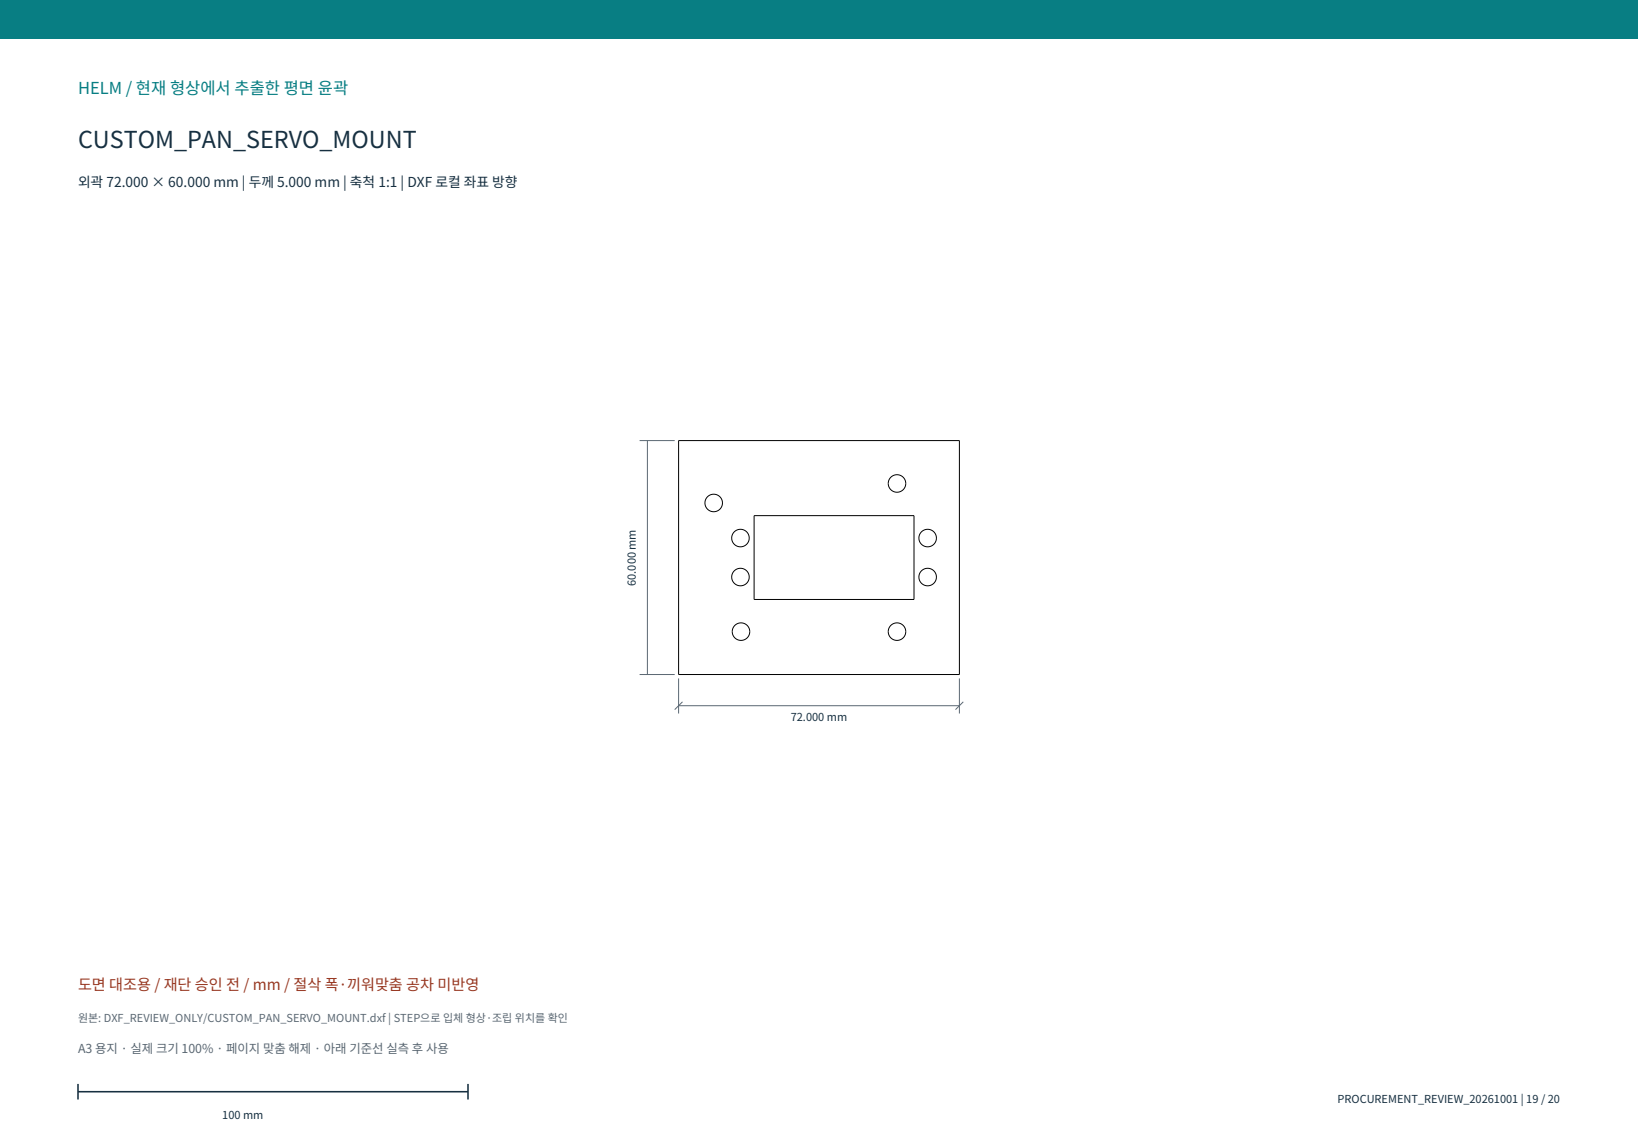
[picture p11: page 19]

도면 대조용 / 재단 승인 전 / mm / 절삭 폭·끼워맞춤 공차 미반영

원본: DXF_REVIEW_ONLY/CUSTOM_PAN_SERVO_MOUNT.dxf | STEP으로 입체 형상·조립 위치를 확인

A3 용지 · 실제 크기 100% · 페이지 맞춤 해제 · 아래 기준선 실측 후 사용

# CUSTOM_TILT_SERVO_MOUNT

### 외곽 72.000 × 49.000 mm | 두께 5.000 mm | 축척 1:1 | DXF 로컬 좌표 방향

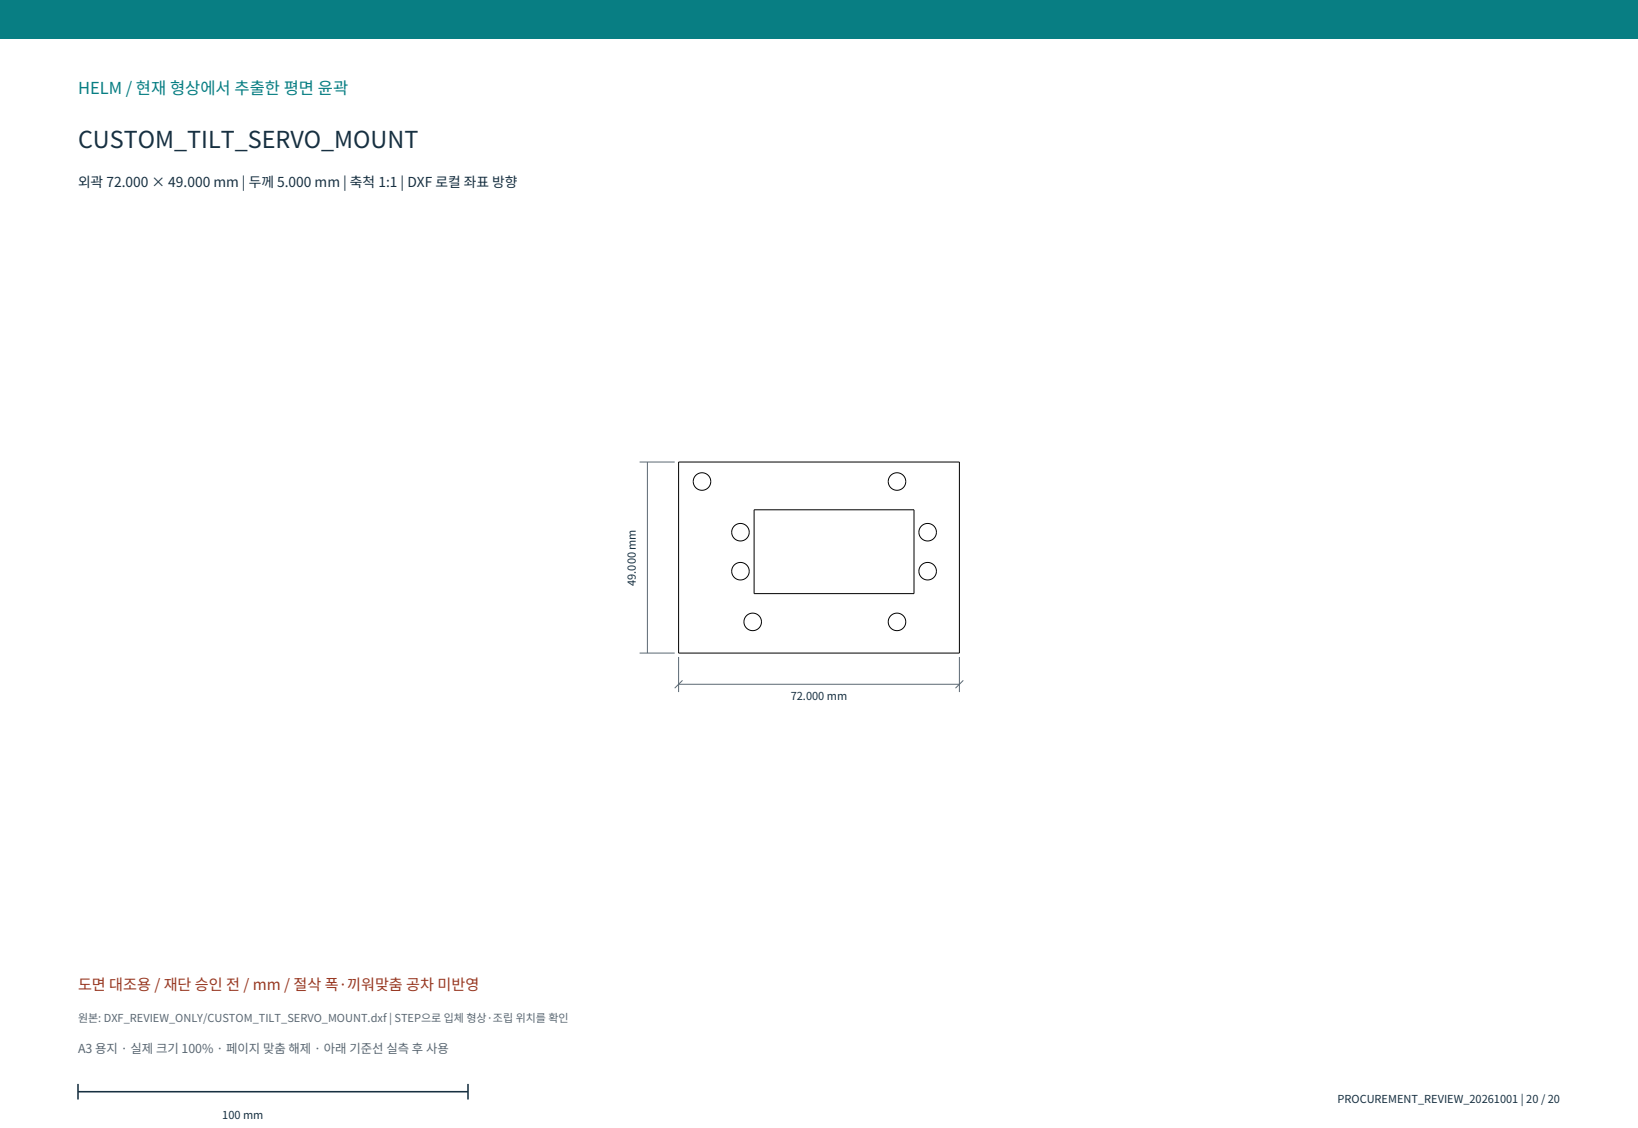
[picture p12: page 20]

도면 대조용 / 재단 승인 전 / mm / 절삭 폭·끼워맞춤 공차 미반영

원본: DXF_REVIEW_ONLY/CUSTOM_TILT_SERVO_MOUNT.dxf | STEP으로 입체 형상·조립 위치를 확인

A3 용지 · 실제 크기 100% · 페이지 맞춤 해제 · 아래 기준선 실측 후 사용

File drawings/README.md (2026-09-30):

# 자료 안내

V13은 전체 과거 도면 202쪽, SER0063는 최신 변경 안내 6쪽입니다. 최신 재단 승인본이 아닙니다.

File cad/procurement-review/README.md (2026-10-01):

# 현재 구매품 반영 CAD - 검토본

PROCUREMENT_REVIEW_20261001, 전체 4,078개 노드. 제조 승인 전.

- [part-step](part-step/): 현재 제작 대상 128개. 모두 포맥스 평판이라는 뜻은 아닙니다.
- [purchased-step](purchased-step/): 변경 4개 형상. 전원판은 위 폴더와 중복입니다.
- [dxf-review-only](dxf-review-only/): 일정 두께 확인한 20개 관통 윤곽, 공차·절삭 폭 미반영.
- [source](source/): 생성·검사·도면 코드와 제조사 열화상 원본.

전체 STEP·현재 BREP 편집 스냅샷은 [ZIP 복원](../../docs/11-artifacts.md)으로 받습니다. [추가 자료](../../docs/15-needed-measurements.md).

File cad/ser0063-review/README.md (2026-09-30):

# 자료 안내

현재 모터 교체 검토본입니다. part-step 17개, dxf-review-only 7개. 전체 STEP은 최신 아카이브를 복원해 여세요. source는 원 실행 코드이며 기준 캐시·경로 준비가 필요합니다.

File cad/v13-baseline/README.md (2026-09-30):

# 자료 안내

과거 V13 기준의 130개 부품 STEP과 54개 DXF입니다. 최신 카메라 변경과 혼용하지 않습니다.

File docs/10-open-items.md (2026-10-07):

# 겹침과 미확정 체결부

MEASURED_LAYOUT_20261006. 0.5 mm³ 초과 교집합을 기록했습니다. C920 내부 참조 형상·홀 없는 외곽 모델을 포함하므로 전부 실물 충돌로 단정하지 않습니다. 실제 고정부 재구성과 회전 검사가 필요합니다.

## 변경부 정지 상태 24쌍

| 형상 A | 형상 B | 부피 mm³ | 분류 |
|---|---|---:|---|
| APPROX_BACKPLANE_L_0 | APPROX_SMALL_L_0_23_LEFT | 18.000 | 실물 체결·홀·배치 확인 필요 |
| APPROX_BACKPLANE_L_0 | CUSTOM_LEFT_GUIDE_FOOT_0 | 44.400 | 실물 체결·홀·배치 확인 필요 |
| APPROX_BACKPLANE_L_0 | FUSE_SHELF_0_LOWER | 10.603 | 실물 체결·홀·배치 확인 필요 |
| APPROX_BACKPLANE_L_0 | FUSE_SHELF_0_SPACER | 31.809 | 실물 체결·홀·배치 확인 필요 |
| APPROX_BACKPLANE_L_0 | LEFT_FOOT_0_-86.38295281832514 | 18.850 | 실물 체결·홀·배치 확인 필요 |
| APPROX_BACKPLANE_L_0 | LEFT_FOOT_W_0_-86.38295281832514 | 9.947 | 실물 체결·홀·배치 확인 필요 |
| APPROX_BACKPLANE_L_1 | FUSE_SHELF_1_LOWER | 10.603 | 실물 체결·홀·배치 확인 필요 |
| APPROX_BACKPLANE_L_1 | FUSE_SHELF_1_SPACER | 31.809 | 실물 체결·홀·배치 확인 필요 |
| APPROX_CAM_L_RIGHT | CUSTOM_PAN_ARM_RIGHT | 52.438 | 실물 체결·홀·배치 확인 필요 |
| APPROX_MEDIUM_L_0 | CUSTOM_LEFT_GUIDE_FOOT_0 | 30.411 | 실물 체결·홀·배치 확인 필요 |
| APPROX_MEDIUM_L_0 | LEFT_A_F_0_1 | 14.137 | 실물 체결·홀·배치 확인 필요 |
| APPROX_MEDIUM_L_0 | LEFT_FOOT_0_-70.38295281832514 | 12.566 | 실물 체결·홀·배치 확인 필요 |
| APPROX_MEDIUM_L_1 | CUSTOM_LEFT_GUIDE_FOOT_1 | 42.527 | 실물 체결·홀·배치 확인 필요 |
| APPROX_MEDIUM_L_1 | LEFT_A_F_1_0 | 14.137 | 실물 체결·홀·배치 확인 필요 |
| APPROX_MEDIUM_L_1 | LEFT_FOOT_1_70.38295281832514 | 12.566 | 실물 체결·홀·배치 확인 필요 |
| APPROX_MEDIUM_L_1 | LEFT_FOOT_1_86.38295281832514 | 1.320 | 실물 체결·홀·배치 확인 필요 |
| APPROX_MEDIUM_L_1 | RELAY_TRAY_0_SPACER | 6.137 | 실물 체결·홀·배치 확인 필요 |
| APPROX_SMALL_L_0_23_LEFT | CUSTOM_POWER_BACKPLANE | 27.000 | 실물 체결·홀·배치 확인 필요 |
| APPROX_SMALL_L_1_245_RIGHT | D5_LOW1 | 12.375 | 실물 체결·홀·배치 확인 필요 |
| APPROX_SMALL_L_1_245_RIGHT | D5_LOW3 | 12.731 | 실물 체결·홀·배치 확인 필요 |
| COMMUNITY_C920_0 | COMMUNITY_C920_2 | 39.757 | C920 내부 참조 형상 |
| COMMUNITY_C920_1 | COMMUNITY_C920_3 | 718.152 | C920 내부 참조 형상 |
| COMMUNITY_C920_2 | COMMUNITY_C920_4 | 137.718 | C920 내부 참조 형상 |
| COMMUNITY_C920_5 | COMMUNITY_C920_6 | 4.899 | C920 내부 참조 형상 |

## 카메라 자세 검사 고유 10쌍

| 형상 A | 형상 B | 검사 자세 팬/틸트 ° | 최대 부피 mm³ |
|---|---|---|---:|
| APPROX_CAM_L_LEFT | CUSTOM_C920_SADDLE | -45/-20, 0/-20, 45/-20 | 121.783 |
| APPROX_CAM_L_LEFT | CUSTOM_TILT_CHEEK_LEFT | -45/-20, 0/-20, 45/-20 | 40.594 |
| APPROX_CAM_L_RIGHT | CUSTOM_C920_SADDLE | -45/-20, 0/-20, 45/-20 | 38.971 |
| APPROX_CAM_L_RIGHT | CUSTOM_TILT_CHEEK_RIGHT | -45/-20, 0/-20, 45/-20 | 40.594 |
| CUSTOM_PAN_ARM_RIGHT | CUSTOM_TILT_CORNER_RIGHT0_V | -45/-20, -45/0, -45/20, 0/-20, 0/0, 0/20, 45/-20, 45/0, 45/20 | 57.705 |
| CUSTOM_PAN_ARM_RIGHT | CUSTOM_TILT_CORNER_RIGHT1_V | -45/-20, -45/0, -45/20, 0/-20, 0/0, 0/20, 45/-20, 45/0, 45/20 | 57.705 |
| CUSTOM_PAN_YOKE | CUSTOM_TILT_CORNER_LEFT0_F | -45/-20, 0/-20, 45/-20 | 16.991 |
| CUSTOM_PAN_YOKE | CUSTOM_TILT_CORNER_LEFT1_F | -45/20, 0/20, 45/20 | 16.991 |
| CUSTOM_PAN_YOKE | CUSTOM_TILT_CORNER_RIGHT0_F | -45/-20, 0/-20, 45/-20 | 16.991 |
| CUSTOM_PAN_YOKE | CUSTOM_TILT_CORNER_RIGHT1_F | -45/20, 0/20, 45/20 | 16.991 |

팬 ±45°·틸트 ±20°는 검사한 자세일 뿐 승인 범위가 아닙니다. 연속 회전·공차·강도·가동 배선을 보증하지 않습니다.

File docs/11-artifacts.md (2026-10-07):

# 수정 CAD와 파일 복원

현재 검토본은 **MEASURED_LAYOUT_20261006**입니다. 전달한 전체 ZIP은 276,698,242바이트, SHA-256 `232775f755a6a90daa2d70e75ed116a9935b29ed06ccb87935e140dc86a2117a`입니다. 전체 STEP·편집 BREP·128개 제작 STEP·20개 DXF·부품표·도면·원본 치수표를 포함합니다.

GitHub에는 기존 전체 기준본과 변경 BREP·전체 편집 메타데이터를 담은 4.1MB 델타를 함께 보관합니다. **델타만으로 전체 CAD가 되지는 않습니다.** 다음 두 ZIP을 결합하면 편집 파일 3,897개의 해시를 모두 대조합니다.

```bash
python tools/restore_archives.py --archive procurement-review-20261001
python tools/restore_archives.py --archive measured-editable-delta-20261006
python cad/measurements-20261006/source/restore_measured.py --baseline downloads/HELM_PROCUREMENT_CAD_REVIEW_20261001.zip --delta downloads/HELM_MEASURED_EDITABLE_DELTA.zip --output downloads/measured
```

STEP 재생성은 [도출 과정](12-reproduce.md)을 따릅니다. STEP 헤더의 생성 시각 등은 재생성 때 달라질 수 있습니다. 편집 BREP 해시와 형상·치수 대조로 복원을 판단합니다. 델타 내부의 예전 내보내기 기록 대신 [최신 STEP 검사](../data/measurements-20261006/FULL_STEP_READBACK.json)를 참고합니다.

[부품번호·실측 적용표](../data/measurements-20261006/HELM_부품번호_실측적용표.xlsx) · [도면](../drawings/measurements-20261006/) · [재생성 소스](../cad/measurements-20261006/source/) · [백업 조각과 해시](../archives/manifest.json)

원본 LICENSE와 출처를 보존했습니다. GitHub Release/LFS 업로드나 재단·통전 승인을 의미하지 않습니다.

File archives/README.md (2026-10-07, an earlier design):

# CAD와 입력 자료 아카이브

최신 편집 모델은 **기준본 procurement-review-20261001 + measured-editable-delta-20261006**을 결합해 복원합니다. [전체 복원 명령](../docs/11-artifacts.md)을 따르세요. 각 part 파일은 개별 ZIP이 아닙니다.

측정 델타 ZIP: 4,059,445바이트 / 17조각 / SHA-256 `28bc90890de76f5c3b2eefee8ada1eb0d5a57adcde6a709c5c8b1a4753e478d0`. 변경 BREP 26개와 전체 편집 메타데이터·치수 근거를 포함합니다. 원본 기준본과 결합하여 편집 파일 3,897개를 바이트 단위로 대조합니다.

이전 네 아카이브와 해시는 [manifest.json](manifest.json)에 그대로 보존합니다. `restore_archives.py`의 인자 없는 기본값은 의존 기준본 procurement-review-20261001입니다. 최신 모델 전체로 오해하지 마세요.

```bash
python tools/restore_archives.py --all --verify-only
```

이 백업은 파일 복원용이며 제조 승인이나 GitHub Releases/LFS 설정을 의미하지 않습니다.

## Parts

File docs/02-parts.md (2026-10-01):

# 구매 부품 적용 기준

1. 1차는 이전 CSV 왼쪽 29품목, 2차는 이번 XLSX `2주차!A20:I83` 64행입니다.
2. 비교견적 시트와 이전 CSV 오른쪽 과거 계획을 추가 재고로 합산하지 않습니다.
3. 새 품목 전체를 장착하지 않습니다. 실제 대체품과 CAD가 다르면 수정합니다.
4. 없는 부품을 새로 구매했다고 가정하지 않습니다. 보유품으로 해결되지 않으면 구조·기능을 미확정으로 기록합니다.

[1차 목록](parts/first-purchase.md) · [2차 목록](parts/second-purchase.md) · [원문 행/링크](../data/purchases/source-rows.json)

| 항목 | 이전 → 이번 구매 | 현재 판단 |
|---|---|---|
| 카메라 서보 | MG90S → SER0063 ×2, 30행 | 몸체 교체 완료, 혼 미확정 |
| 서보 브래킷 | 기존 소형 구조 → MG995/MG996용 ×2, 78행 | 내측 폭·구멍·두께 실측 전 호환 단정 불가 |
| SSD | WD SN530 2242 → KLEVV CRAS C715, 83행 | 512GB 선택·명목 치수 확인, 실제 2280 위치에 적용; 실물 끼움·나사는 보류 |
| 배전 | 기존 모델 → SZH-CP003, 79행 | 100×45×33 mm 외곽 적용; 상세 고정홀·단자·덮개·정격은 보류 |
| 열화상 | 기존 MLX90640 보드 → SEENGREAT [220565], 25행 | 제조사 STEP 215개 형상 대조·본체 유지, PH2.0 정정; 결합 방향 보류 |
| USB 허브 | 기존 참조 형상 → NEXT-505UHP, 42행 | 101×41×25 mm 외형 일치; 포트·전원·케이블 확인 필요 |
| 충전기 | EO-1220 → EO-1212, 20행 | 새 모델 기록, 차체 장착 강제하지 않음 |
| 판재 | 5T 포맥스 600×900 ×2, 51행 | 재료 기준, 전체 네스팅 미완료 |
| 전산볼트 | M4×1m ×5, 52행 | 카메라 지지부 일부에 적용 |
| 체결품 | 혼합 세트·M4 풀림방지 너트 | 일반 너트와 높이/개수 동일하다고 가정하지 않음 |
| LED·데스크 스피커 | 전시 패널·Edifier, 81-82행 | 전시용 가능, 차체에 강제 배치하지 않음 |
| 공구·소모품 | 드릴·톱·줄·클램프·납땜·배선 재료 | 제작/시험 준비물로 관리 |

ADS1115 모듈은 구매 목록에 없어 받침·관련 체결품과 가짜 연결을 제거했습니다. 전압 취득 회로는 미확정입니다. 일부 M2/M2.5 체결품, 특수 스페이서·범퍼 스프링은 보유 확인이 필요합니다. 회로 받침 CAD나 모델 노드가 있다고 해당 회로/부품을 구매한 것은 아닙니다.

체결 세트·스페이서·벨크로·공구·EVA·나사고정제 등의 설명과 수량 열에는 해석 차이가 있습니다. 포장별 실제 규격·개수를 기록하세요. CAD 노드 수를 구매 수량으로 읽지 않습니다.

[사진 대조](14-product-photo-review.md) · [추가 자료](15-needed-measurements.md) · [가정 노드](../data/procurement-review/ASSUMPTION_REGISTER.json)

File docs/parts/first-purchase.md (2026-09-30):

# 1차 구매 목록

이전 CSV의 왼쪽 원문 5-33행입니다. 오른쪽 과거 2차 계획은 최신 2차 자료가 아닙니다.

수량은 원문의 수량 칸입니다. 모델명 속 포장 수량을 곱해 재고를 임의로 계산하지 않습니다. [구매 링크·원문 행](../../data/purchases/source-rows.json)

| ID | 품목·설명 | 모델 | 수량 |
|---|---|---|---:|
| P1-001 | 메인 연산 보드 | NVIDIA Jetson Orin Nano Super Developer Kit 8GB | 1 |
| P1-002 | 저장장치 | WD SN530 NVMe 2242 SSD 256GB | 1 |
| P1-003 | 비전 카메라 | Logitech C920 1080p USB 웹캠 | 1 |
| P1-004 | 라이다 | SLAMTEC RPLIDAR A2M12 | 1 |
| P1-005 | 저수준 제어보드 | ESP32 USB C 타입 아두이노 개발 보드 DevikitC V 38핀 | 1 |
| P1-006 | 이동 섀시 | Hiwonder 서스펜션 궤도형 섀시·엔코더 모터 구성 | 1 |
| P1-007 | 모터 드라이버 | [Cytron] 10Amp 5V-30V DC Motor Driver (2 Channels) [MDD10A] | 1 |
| P1-008 | 관성측정센서 | Adafruit BNO085 IMU | 1 |
| P1-009 | 배터리 | ROCKET ES7-12 12V 7Ah AGM 배터리 | 1 |
| P1-010 | 배터리 충전기 | 이오전자 EO-1220 12V 2A 연축전지 충전기 | 1 |
| P1-011 | 5V 전원 변환기 | SZH-EK366 5V 5A DC-DC 스텝다운 컨버터 | 1 |
| P1-012 | 비상정지 장치 | 22mm 래칭형 Mushroom E-STOP 1NO1NC | 1 |
| P1-013 | 모터 전원 차단장치 | 12V 40A 4핀 릴레이·소켓 배선 세트 | 1 |
| P1-014 | 접촉 감지 센서 | V-J166-1C25 리미트 스위치 ×4 | 4 |
| P1-015 | 메인 퓨즈 홀더 | 자동차용 Blade Fuse Holder ×1 | 1 |
| P1-016 | 분기 퓨즈 홀더 | 차량용 퓨즈박스 4구 키트 SZH-JA020 | 1 |
| P1-017 | 퓨즈 | 차티스트 자동차용 ATO Blade Fuse 10종 세트 | 1 |
| P1-018 | 배전 장치 | 접지부스바·DC 배전 단자대 ×2 | 2 |
| P1-019 | 모터 전원 배선 | 14AWG 적색·흑색 2P 실리콘 케이블 2m | 2 |
| P1-020 | 신호 배선 | 22AWG 적색·흑색 2P 실리콘 케이블 2m | 2 |
| P1-021 | 커넥터 | JST SH 1.0mm 피치 6핀 포함 와이어 커넥터 세트 28AWG | 1 |
| P1-022 | 압착단자 | 터미널 압착 단자 320p 세트 전선 연결 배선 커넥터 | 1 |
| P1-023 | 통신 케이블 | 개발용 USB A to USB C 데이터 케이블 1M | 1 |
| P1-024 | 고정부품 | M3 나일론 스페이서·볼트 세트 | 1 |
| P1-025 | 음성 경보장치 | 휴대형 USB 스피커 | 1 |
| P1-026 | 배터리 모니터링 | 아두이노 전압 측정 0~25V 전압 센서 모듈 | 1 |
| P1-027 | 전원 설계 | 5개 Type-C MT3608 DC-DC 가변 승압 모듈 2A 스텝업 컨버터 | 1 |
| P1-028 | 통신 부품 | 에즈윈 인텔 AX210 Wi-Fi 6E Kit 무선랜카드 | 1 |
| P1-029 | 메인 전원 스위치 | 12V 20A LED 원형 로커 스위치 3핀 차량·선박 겸용 2pcs | 1 |

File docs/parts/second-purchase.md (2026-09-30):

# 2차 구매 목록

이번 XLSX의 2주차 A20:I83, 64행입니다. 비교견적은 추가 구매품으로 세지 않았습니다.

수량은 원문의 수량 칸입니다. 모델명 속 포장 수량을 곱해 재고를 임의로 계산하지 않습니다. [구매 링크·원문 행](../../data/purchases/source-rows.json)

| ID | 품목·설명 | 모델 | 수량 |
|---|---|---|---:|
| P2-R20 | 배터리 충전기 | 이오전자 EO-1212 12V 1.2A 연축전지 자동충전기 | 1.0 |
| P2-R21 | 커넥터 | JST-PH 6핀 케이블 2.0mm 피치 같은면 1대N(30cm ×4) | 8.0 |
| P2-R22 | 전원 설계 | 12V→19V DC 승압 컨버터 190W | 1.0 |
| P2-R23 | Jetson 전원 커넥터 | [Switchcraft Inc.] 760K | 2.0 |
| P2-R24 | 리미트 스위치 단자 | [TE Connectivity AMP Connectors] 2-520181-2 | 24.0 |
| P2-R25 | - | [SEENGREAT] 열화상 카메라 모듈 IR MLX90640 [220565] | 1.0 |
| P2-R26 | 퓨즈 홀더 - FHAC0002LXN | [Littelfuse Inc.] FHAC0002LXN | 2.0 |
| P2-R27 | 멀티미터(전기 측정) | [UNI-T] 디지털 클램프(후쿠메타)미터 UT210E | 1.0 |
| P2-R28 | 배터리용 암 압착단자(+) | 아트얼스 PG 압착 터미널 절연 단자 FDFD 5.5-250 전기 전선 케이블 배선 평단자 6.3mm 옐로우 PG24A | 5.0 |
| P2-R29 | 동일규격 / 6.3mm 평단자 / 1개 단가 검색결과 기준 | PG 압착 터미널 절연 단자 FDFD 2-250 전기 전선 케이블 배선 평단자 6.3mm 블루 PG15A | 5.0 |
| P2-R30 | 서보모터(카메라 움직임) | [DFRobot] SER0063 | 2.0 |
| P2-R31 | 릴레이 보호 다이오드 | (10개/세트) 1N4007 정류 다이오드 - 1A 1000V 고전압 DO-41 패키지 - 역전류 방지 전자부품 | 1.0 |
| P2-R32 | 절연단자 압착기 | IWISS 터미널압착기 PG단자 압착공구 HS-30J | 1.0 |
| P2-R33 | 와이어 스트리퍼 | 엔지니어 스트리퍼 PAW-31 전선 와이어 피복 탈피 | 1.0 |
| P2-R34 | 인두기 | [하코 HAKKO] 온도조절인두기 FX-600 (T18-B 인두팁 포함) | 1.0 |
| P2-R35 | 납 | [Singapore Asahi] 스프링 무연납 SCS7(P3.5) - 0.8mm (10g/1.8M) | 4.0 |
| P2-R36 | 인두 거치대 | 스프링형 인두기 거치대 스텐드 납땜기 철제 받침대 걸이 | 1.0 |
| P2-R37 | 유사사양 / 127pcs 열수축튜브 세트 | 열 선보호 수축튜브 127pcs 블랙 세트 | 1.0 |
| P2-R38 | 히트건 | 홈플래닛 1800W 열풍기 히팅건 | 1.0 |
| P2-R39 | 볼트/너트 세트 | [로보티즈] 볼트너트 세트 BNS-30 | 1.0 |
| P2-R40 | 케이블타이 | 얇은 케이블타이 100pcs 블랙/화이트 thin cable tie | 1.0 |
| P2-R41 | 테이프 | 쿠말 접착 초강력 벨크로 테이프 갈고리면 20mm x 5m + 부착면 20mm x 5m 세트, 화이트, 3세트 | 1.0 |
| P2-R42 | USB 3.0 유전원 허브 4포트 | 넥스트유 USB 3.0 4포트 유전원 허브 케이블일체형 NEXT 505UHP + 어댑터 | 1.0 |
| P2-R43 | USB A to C 데이터 케이블 1M | coms ABFC100 USB A to C타입 케이블 1M 블랙 데이터 충전 | 2.0 |
| P2-R44 | Micro USB 데이터 케이블 1M | 개발용 마이크로 USB 케이블 | 2.0 |
| P2-R45 | DP to HDMI 케이블/어댑터 | DP to HDMI 2.1 8K@60Hz 케이블 3m | 1.0 |
| P2-R46 | CAT.6 랜선 3m | 랜스타 UTP CAT.6 다이렉트 랜 케이블 x 3 | 2.0 |
| P2-R47 | 3M 절연테이프 | [YM] 3M 전기 절연 비닐테이프 1711 | 2.0 |
| P2-R48 | 납땜 플럭스펜 | 납땜 플럭스 펜 10ml 태양 전지 공정 무세척 DIY 케스터 용접, 플럭스펜  GD24062 3개 | 1.0 |
| P2-R49 | 솔더윅/납 제거선 | 솔더윅 솔더위크 납땜 제거 흡입기 디솔더링, 2개 | 1.0 |
| P2-R50 | 동일규격 / 20cm / 암암·암수·수수 3종 점퍼케이블 | JK 브레드보드 점퍼선 점퍼 케이블 40P 암컷 숫컷 아두이노 40가닥 DIY 와이어 | 1.0 |
| P2-R51 | 포맥스판 / 5T / 600×900mm / 백색 / 구조 장착판 가공용 | 포멕스판 (600mmx900mm)5T 백색/포멕스&포맥스 | 2.0 |
| P2-R52 | 동일규격 / M4 / 1m / 철 전산볼트 / 색상·도금 차이 가능 | [새한볼트] 전산볼트(노란도금) M4-1M | 5.0 |
| P2-R53 | M4 너트/와셔 포함 체결 세트 / SUS304 / M3·M4·M5 혼합 / 2세트 | 스텐 둥근 냄비 머리 볼트 너트 와셔 세트 600SET SUS304 M3 M4 M5 | 1.0 |
| P2-R54 | ㄱ자/L자 브라켓 / 소형 / 20개 / 센서·소형 판재 고정용 | 네이쳐툴 ㄱ자 선반 꺽쇠 코너 기억자 코너철 소형, 소형, 20개 | 1.0 |
| P2-R55 | ㄱ자/L자 브라켓 / 중형 / 20개 / 상판·라이다 타워·보강용 | 네이쳐툴 ㄱ자 선반 꺽쇠 코너 기억자 코너철 소형, 중형, 20개 | 1.0 |
| P2-R56 | M3 PCB 스페이서 세트 / 260P / 보드 절연·고정용 / 2세트 | 260P M3 나일론 스페이서 너트 세트 - 육각 기판 고정용 나사 키트 - PCB 조립용 | 1.0 |
| P2-R57 | 동일제품 / 25mm×0.9m / 흑색 / 배터리·부품 고정용 / 3개 기준 | 벨크로 찍찍이 세트 25mm x 0.9m 흑색 다용도 고정 스트랩 1개입 커머스픽101 | 1.0 |
| P2-R58 | 포맥스 커터/아크릴 커터 / 기본칼날 3p + 추가칼날 10p / 2세트 | 모나코올리브 아크릴 커터 컷팅 칼 + 기본칼날 3p + 추가칼날 10p 세트, 2세트 | 1.0 |
| P2-R59 | 스탠맨 21V 무선충전 해머전동드릴 공구세트 / ST-6000 / 1세트 | 스탠맨 ST-6000 (2.0Ah, 배터리 1개) | 1.0 |
| P2-R60 | HSS 메탈 드릴비트 / 2~8mm / 6종 / 2607010529 / 2세트 | 보쉬 PRO HSS 메탈 드릴비트 6종 세트 2~8mm / 2607010529., 2세트 | 1.0 |
| P2-R61 | Mini Hacksaw DL353312 / 300mm·12인치 / Bi-metal 톱날 / 2개 | 델리툴즈 경량 톱 쇠톱 미니 12인치 줄톱 톱대 | 1.0 |
| P2-R62 | PH1·PH2·일자 5mm·6.5mm / 4PCS / DWHT65101 | [디월트] 스크류드라이버 4 PCS 세트 DWHT65101 | 1.0 |
| P2-R63 | 니퍼 / 150mm / BST-13203 / 1개 | BESTIR 니퍼 150mm BST-13203, 1개 | 1.0 |
| P2-R64 | 니들 롱노즈 플라이어 / STHT84096-8 / 5인치급 / 1개 | STANLEY 니들 롱로즈 플라이어 스탠리STHT84096-8 롱로우즈 롱노즈플라이어 롱로즈 | 1.0 |
| P2-R65 | 정밀 줄 세트 / 10종 / 2세트 | G.L.S 정밀 줄 세트 10종 줄세트 | 1.0 |
| P2-R66 | 240·320·400·600·800·1000·1200·1500·2000 grit / 2세트 | 샌드페이퍼 240/320/400/600/800/1000/1200/1500/2000 그릿 사포 물/건식 샌딩페이퍼 연마재 | 1.0 |
| P2-R67 | C형/G형 클램프 / 4인치 / 최대 105mm / 2개입 | C형 클램프 4인치 105mm G형 목공용, 2개 | 1.0 |
| P2-R68 | 투명 방풍 고글/보안경 | 엠믹스 김서림방지 고글 보안경 작업용 보호안경 MX-B1 | 1.0 |
| P2-R69 | Melange Gray × L × 3개 | 쓰리엠 컴포트 그립 터치 양손세트 | 1.0 |
| P2-R70 | 스텐/철제 직자 / 60cm / 1개 | 철자 스틸자 스텐자 직자 60CM 철제자 커팅자 | 1.0 |
| P2-R71 | 미니 양구 스패너 / 3·4·5·6·7·8·10·11·13mm / 9종 / 1세트 | 스마토 미니 양구 스패너 9종 세트 SM-MOW9P, 1세트 | 1.0 |
| P2-R72 | 볼 L형 육각렌치 / mm 규격 / 1.5·2·2.5·3·4·5·6·8·10mm / 9pcs | 일제 육각렌치 볼 L 엘렌치 세트 미리 mm 렌찌 9pcs | 1.0 |
| P2-R73 | ESC-4S / HSS / 4~12·4~20·4~32mm / 2세트 | [이엑스파워] 스텝드릴 세트 ESC-4S | 1.0 |
| P2-R74 | 400핀 Half Size Breadboard / SZH-BBAD-005 / 5개 | [SMG] 브레드보드 400핀 Half Size Breadboard [SZH-BBAD-005] | 5.0 |
| P2-R75 | 스텐 나일론너트 M4 × 1개 | 하나로볼트 스텐 나일론 너트 볼트 풀림방지 M3 M4 M5 M6 M8 M10 M12 M16 M20, 1개 | 100.0 |
| P2-R76 | 고밀도 EVA 방진패드 / 블랙 / 8cm × 8cm / 2P / 5세트 기준 | 고밀도 EVA 방진패드 충격흡수패드 | 3.0 |
| P2-R77 | 록타이트 222 / 저강도 / 5g / 3개 기준 | 록타이트 222 나사고정제 5g 저강도 볼트 너트 소형 나사고정제 나사풀림방지 | 2.0 |
| P2-R78 | 아두이노 MG995 MG996용 서보모터 브라켓 | 아두이노 MG995 MG996용 서보모터 브라켓 METAL-BRACKET | 2.0 |
| P2-R79 | 입력 2, 출력 8, 모델명 SZH-CP003 | [SMG] 전원분배 단자대 / 터미널블럭 (입력2, 출력8)[SZH-CP003] | 1.0 |
| P2-R80 | 3핀 JR/Futaba 계열, 길이 30cm, 모델명 MAC-029 | [Yeahbot] 서보 연장 케이블 30cm [MAC-029] | 5.0 |
| P2-R81 | 전시 패널 | LED 라이트패널 실내용 벽걸이 엘이디광고패널 | 1.0 |
| P2-R82 | 음향장치 스피커 | [한국 정발] 에디파이어 PC-FI 데스크 파이 스튜디오 모니터 스피커 | 1.0 |
| P2-R83 | 저장장치 | ESSENCORE KLEVV CRAS C715 M.2 NVMe 파인인포 | 1.0 |

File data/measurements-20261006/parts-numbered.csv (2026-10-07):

number | purchase_id | round | source_row | item | model | quantity_source | measurement_number | evidence_type | dimensions_mm | decision | action | cad_usage | cad_nodes | node_examples | source_url | quantity_caution
1 | P1-001 | 1차 | 5 | 메인 연산 보드 | NVIDIA Jetson Orin Nano Super Developer Kit 8GB | 1 |  | 이전 CAD/상품 자료 (실측 기록 없음) |  | 현장 조정 | 현장 상황에 따라 위치·고정·길이를 유연하게 조정. 강제 끼움/기판 홀 확대는 하지 않음 | CAD 적용/재료 후보 | 1918 | OFFICIAL_JETSON_0000_Solid; OFFICIAL_JETSON_0001_Shell; OFFICIAL_JETSON_0002_Solid; OFFICIAL_JETSON_0003_Shell | https://www.devicemart.co.kr/goods/view?no=14990359 | 수량 셀과 상품명 묶음 수량을 임의 곱셈하지 않음
2 | P1-002 | 1차 | 6 | 저장장치 | WD SN530 NVMe 2242 SSD 256GB | 1 |  | 구매 기록 |  | 측정 불필요 | P2-R83 C715 2280으로 교체됨. 예비 2242를 현재 슬롯에 강제 장착하지 않음 | 교체된 예비품 | 0 |  | https://www.coupang.com/vp/products/9618266367?itemId=28720133256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 | 수량 셀과 상품명 묶음 수량을 임의 곱셈하지 않음
3 | P1-003 | 1차 | 7 | 비전 카메라 | Logitech C920 1080p USB 웹캠 | 1 | 14 | 사진 근사 실측 | 본체 95 × 20 × 28; 클립 44 × 45 × 18; 접힌 측면 전체 57 | 현장 조정 | 구매 행 22 오기를 모델명으로 원본 7행에 연결. 스트랩·EVA는 실물에 맞춤 | CAD 적용/재료 후보 | 7 | COMMUNITY_C920_0; COMMUNITY_C920_1; COMMUNITY_C920_2; COMMUNITY_C920_3 | https://www.coupang.com/vp/products/7159069983 | 수량 셀과 상품명 묶음 수량을 임의 곱셈하지 않음
4 | P1-004 | 1차 | 8 | 라이다 | SLAMTEC RPLIDAR A2M12 | 1 |  | 이전 CAD/상품 자료 (실측 기록 없음) |  | 현장 조정 | 현장 상황에 따라 위치·고정·길이를 유연하게 조정. 강제 끼움/기판 홀 확대는 하지 않음 | CAD 적용/재료 후보 | 3 | DRAWING_BASED_A2M12_BASE; DRAWING_BASED_A2M12_TURRET; PHOTO_BASED_A2M12_WINDOW | https://www.devicemart.co.kr/goods/view?no=1312730 | 수량 셀과 상품명 묶음 수량을 임의 곱셈하지 않음
5 | P1-005 | 1차 | 9 | 저수준 제어보드 | ESP32 USB C 타입 아두이노 개발 보드 DevikitC V 38핀 | 1 |  | 이전 CAD/상품 자료 (실측 기록 없음) |  | 현장 조정 | 현장 상황에 따라 위치·고정·길이를 유연하게 조정. 강제 끼움/기판 홀 확대는 하지 않음 | CAD 적용/재료 후보 | 31 | ADAPTED_ESP32_38PIN_0; ADAPTED_ESP32_38PIN_1; ADAPTED_ESP32_38PIN_2; ADAPTED_ESP32_38PIN_4 | https://www.coupang.com/vp/products/8756951445?vendorItemId=91072858290&sourceType=CART | 수량 셀과 상품명 묶음 수량을 임의 곱셈하지 않음
6 | P1-006 | 1차 | 10 | 이동 섀시 | Hiwonder 서스펜션 궤도형 섀시·엔코더 모터 구성 | 1 |  | 이전 CAD/상품 자료 (실측 기록 없음) |  | 필수 확인 | 네 점 모두 맞으면 새로 전부 측정할 필요 없음. 다르면 해당 홀 중심 좌표만 측정 | CAD 적용/재료 후보 | 412 | OFFICIAL_CHASSIS_0000_Solid; OFFICIAL_CHASSIS_0001_Solid; OFFICIAL_CHASSIS_0002_Solid; OFFICIAL_CHASSIS_0003_Solid | https://www.coupang.com/vp/products/9358141082 | 수량 셀과 상품명 묶음 수량을 임의 곱셈하지 않음
7 | P1-007 | 1차 | 11 | 모터 드라이버 | [Cytron] 10Amp 5V-30V DC Motor Driver (2 Channels) [MDD10A] | 1 |  | 이전 CAD/상품 자료 (실측 기록 없음) |  | 현장 조정 | 현장 상황에 따라 위치·고정·길이를 유연하게 조정. 강제 끼움/기판 홀 확대는 하지 않음 | CAD 적용/재료 후보 | 168 | OFFICIAL_MDD10A_0000_Solid; OFFICIAL_MDD10A_0001_Solid; OFFICIAL_MDD10A_0002_Solid; OFFICIAL_MDD10A_0003_Solid | https://www.devicemart.co.kr/goods/view?no=1280280 | 수량 셀과 상품명 묶음 수량을 임의 곱셈하지 않음
8 | P1-008 | 1차 | 12 | 관성측정센서 | Adafruit BNO085 IMU | 1 |  | 이전 CAD/상품 자료 (실측 기록 없음) |  | 현장 조정 | 현장 상황에 따라 위치·고정·길이를 유연하게 조정. 강제 끼움/기판 홀 확대는 하지 않음 | CAD 적용/재료 후보 | 55 | OFFICIAL_BNO085_0000_Solid; OFFICIAL_BNO085_0001_Solid; OFFICIAL_BNO085_0002_Solid; OFFICIAL_BNO085_0003_Solid | https://www.devicemart.co.kr/goods/view?no=15530997 | 수량 셀과 상품명 묶음 수량을 임의 곱셈하지 않음
9 | P1-009 | 1차 | 13 | 배터리 | ROCKET ES7-12 12V 7Ah AGM 배터리 | 1 | 2 | 실측 | 151 × 65 × 94 (케이스); 공식 단자 포함 98 | 현장 조정 | 단자에 연결한 케이블 여유를 남기고 벨크로 길이는 가조립 후 결정 | CAD 적용/재료 후보 | 4 | DRAWING_BASED_ES7_12_BATTERY; PHOTO_BASED_ES7_12_LID; DRAWING_BASED_BATTERY_F2_POS; DRAWING_BASED_BATTERY_F2_NEG | https://www.coupang.com/vp/products/1237358721?vendorItemId=95173570253&sourceType=CART | 수량 셀과 상품명 묶음 수량을 임의 곱셈하지 않음
10 | P1-010 | 1차 | 14 | 배터리 충전기 | 이오전자 EO-1220 12V 2A 연축전지 충전기 | 1 |  | 구매 기록 |  | 측정 불필요 | 도구·소모품·예비/외부 사용품은 CAD에 강제 장착하지 않음 | 미장착·외부 사용·소모품 | 0 |  | https://www.coupang.com/vp/products/5578760518 | 수량 셀과 상품명 묶음 수량을 임의 곱셈하지 않음
11 | P1-011 | 1차 | 15 | 5V 전원 변환기 | SZH-EK366 5V 5A DC-DC 스텝다운 컨버터 | 1 |  | 이전 CAD/상품 자료 (실측 기록 없음) |  | 현장 조정 | 현장 상황에 따라 위치·고정·길이를 유연하게 조정. 강제 끼움/기판 홀 확대는 하지 않음 | CAD 적용/재료 후보 | 11 | PHOTO_BASED_SZH_EK366_BUCK; PHOTO_BASED_BUCK_CAP_200; PHOTO_BASED_BUCK_CAP_244; PHOTO_BASED_EK366_SHIELDED_INDUCTOR | https://www.devicemart.co.kr/goods/view?no=1386375 | 수량 셀과 상품명 묶음 수량을 임의 곱셈하지 않음
12 | P1-012 | 1차 | 16 | 비상정지 장치 | 22mm 래칭형 Mushroom E-STOP 1NO1NC | 1 |  | 이전 CAD/상품 자료 (실측 기록 없음) |  | 필수 확인 | 5T 자투리 끼움+너트 체결 시험과 후면 여유 확인. 맞으면 세부 외형 재측정 불필요 | CAD 적용/재료 후보 | 9 | OFFICIAL_ESTOP_0000_Solid; OFFICIAL_ESTOP_0001_Solid; OFFICIAL_ESTOP_0002_Solid; OFFICIAL_ESTOP_0003_Solid | https://www.coupang.com/vp/products/9546806641 | 수량 셀과 상품명 묶음 수량을 임의 곱셈하지 않음
13 | P1-013 | 1차 | 17 | 모터 전원 차단장치 | 12V 40A 4핀 릴레이·소켓 배선 세트 | 1 |  | 이전 CAD/상품 자료 (실측 기록 없음) |  | 현장 조정 | 현장 상황에 따라 위치·고정·길이를 유연하게 조정. 강제 끼움/기판 홀 확대는 하지 않음 | CAD 적용/재료 후보 | 2 | PHOTO_BASED_RELAY_12V40A; PHOTO_BASED_RELAY_SOCKET | https://www.coupang.com/vp/products/6667848502 | 수량 셀과 상품명 묶음 수량을 임의 곱셈하지 않음
14 | P1-014 | 1차 | 18 | 접촉 감지 센서 | V-J166-1C25 리미트 스위치 ×4 | 4 |  | 이전 CAD/상품 자료 (실측 기록 없음) |  | 필수 확인 | 간이 지그에서 네 방향을 눌러 작동과 복귀를 확인. 미보유 스프링 등을 가상 재고로 취급하지 않음 | CAD 적용/재료 후보 | 20 | APPROX_FRONT_V_J166_BODY; PHOTO_BASED_FRONT_V_J166_LEVER; PHOTO_BASED_FRONT_V_J166_ROLLER; DRAWING_BASED_FRONT_SWITCH_TAB_0 | https://www.devicemart.co.kr/goods/view?no=1327040 | 수량 셀과 상품명 묶음 수량을 임의 곱셈하지 않음
15 | P1-015 | 1차 | 19 | 메인 퓨즈 홀더 | 자동차용 Blade Fuse Holder ×1 | 1 |  | 구매 기록 |  | 측정 불필요 | 현재 FHAC0002LXN(P2-R26) 형상 사용. 동일 기능의 예비 홀더 | 대체/예비 | 0 |  | https://www.coupang.com/vp/products/8457484950 | 수량 셀과 상품명 묶음 수량을 임의 곱셈하지 않음
16 | P1-016 | 1차 | 20 | 분기 퓨즈 홀더 | 차량용 퓨즈박스 4구 키트 SZH-JA020 | 1 | 9 | 실측 | 53 × 86 × 42 | 현장 조정 | 덮개 탈착·퓨즈 교체 공간을 실물로 확인 | CAD 적용/재료 후보 | 2 | PHOTO_BASED_SZH_JA020_BASE; PHOTO_BASED_FUSEBLOCK_COVER | https://www.devicemart.co.kr/goods/view?no=14042045 | 수량 셀과 상품명 묶음 수량을 임의 곱셈하지 않음
17 | P1-017 | 1차 | 21 | 퓨즈 | 차티스트 자동차용 ATO Blade Fuse 10종 세트 | 1 |  | 이전 CAD/상품 자료 (실측 기록 없음) |  | 현장 조정 | 현장 상황에 따라 위치·고정·길이를 유연하게 조정. 강제 끼움/기판 홀 확대는 하지 않음 | CAD 적용/재료 후보 | 4 | DRAWING_BASED_ATO_FUSE_0; DRAWING_BASED_ATO_FUSE_1; DRAWING_BASED_ATO_FUSE_2; DRAWING_BASED_ATO_FUSE_3 | https://www.coupang.com/vp/products/9417130245 | 수량 셀과 상품명 묶음 수량을 임의 곱셈하지 않음
18 | P1-018 | 1차 | 22 | 배전 장치 | 접지부스바·DC 배전 단자대 ×2 | 2 | 11 | 근사 실측 | ≈165 × 15 × 18, 2개 | 현장 조정 | 채택할 때 고정홀 전사. 단자 수·내부 연결·극 배정은 별도 확인 | 선택 재고 외곽 STEP / 본체 미장착 | 0 |  | https://www.coupang.com/vp/products/9172551975 | 수량 셀과 상품명 묶음 수량을 임의 곱셈하지 않음
19 | P1-019 | 1차 | 23 | 모터 전원 배선 | 14AWG 적색·흑색 2P 실리콘 케이블 2m | 2 |  | 이전 CAD/상품 자료 (실측 기록 없음) |  | 현장 조정 | 현장 상황에 따라 위치·고정·길이를 유연하게 조정. 강제 끼움/기판 홀 확대는 하지 않음 | CAD 적용/재료 후보 | 204 | STANDARD_PLUG_HUB_USB0_SHELL; STANDARD_PLUG_HUB_USB0_TONGUE; STANDARD_PLUG_HUB_USB0_CONTACT_0; STANDARD_PLUG_HUB_USB0_CONTACT_1 | https://www.coupang.com/vp/products/8913656765 | 수량 셀과 상품명 묶음 수량을 임의 곱셈하지 않음
20 | P1-020 | 1차 | 24 | 신호 배선 | 22AWG 적색·흑색 2P 실리콘 케이블 2m | 2 |  | 이전 CAD/상품 자료 (실측 기록 없음) |  | 현장 조정 | 현장 상황에 따라 위치·고정·길이를 유연하게 조정. 강제 끼움/기판 홀 확대는 하지 않음 | CAD 적용/재료 후보 | 204 | STANDARD_PLUG_HUB_USB0_SHELL; STANDARD_PLUG_HUB_USB0_TONGUE; STANDARD_PLUG_HUB_USB0_CONTACT_0; STANDARD_PLUG_HUB_USB0_CONTACT_1 | https://www.coupang.com/vp/products/8913656765 | 수량 셀과 상품명 묶음 수량을 임의 곱셈하지 않음
21 | P1-021 | 1차 | 25 | 커넥터 | JST SH 1.0mm 피치 6핀 포함 와이어 커넥터 세트 28AWG | 1 |  | 구매 기록 |  | 측정 불필요 | 도구·소모품·예비/외부 사용품은 CAD에 강제 장착하지 않음 | 미장착·외부 사용·소모품 | 0 |  | https://www.coupang.com/vp/products/8530719539?vendorItemId=95595284874&sourceType=CART | 수량 셀과 상품명 묶음 수량을 임의 곱셈하지 않음
22 | P1-022 | 1차 | 26 | 압착단자 | 터미널 압착 단자 320p 세트 전선 연결 배선 커넥터 | 1 |  | 구매 기록 |  | 측정 불필요 | 도구·소모품·예비/외부 사용품은 CAD에 강제 장착하지 않음 | 미장착·외부 사용·소모품 | 0 |  | https://www.coupang.com/vp/products/7649011260?vendorItemId=95698277545&sourceType=CART | 수량 셀과 상품명 묶음 수량을 임의 곱셈하지 않음
23 | P1-023 | 1차 | 27 | 통신 케이블 | 개발용 USB A to USB C 데이터 케이블 1M | 1 |  | 이전 CAD/상품 자료 (실측 기록 없음) |  | 현장 조정 | 현장 상황에 따라 위치·고정·길이를 유연하게 조정. 강제 끼움/기판 홀 확대는 하지 않음 | CAD 적용/재료 후보 | 17 | STANDARD_PLUG_ESP32_USB_SHELL; STANDARD_PLUG_ESP32_USB_TONGUE; STANDARD_PLUG_ESP32_USB_CONTACT_0; STANDARD_PLUG_ESP32_USB_CONTACT_1 | https://www.coupang.com/vp/products/8690434145?vendorItemId=92227381628&sourceType=CART | 수량 셀과 상품명 묶음 수량을 임의 곱셈하지 않음
24 | P1-024 | 1차 | 28 | 고정부품 | M3 나일론 스페이서·볼트 세트 | 1 |  | 이전 CAD/상품 자료 (실측 기록 없음) |  | 현장 조정 | 현장 상황에 따라 위치·고정·길이를 유연하게 조정. 강제 끼움/기판 홀 확대는 하지 않음 | CAD 적용/재료 후보 | 492 | M4_CHASSIS_0; M4_CHASSIS_W_0; M4_CHASSIS_N_0; M4_CHASSIS_1 | https://www.coupang.com/vp/products/7354375381?vendorItemId=86059571826&sourceType=CART | 수량 셀과 상품명 묶음 수량을 임의 곱셈하지 않음
25 | P1-025 | 1차 | 29 | 음성 경보장치 | 휴대형 USB 스피커 | 1 |  | 이전 CAD/상품 자료 (실측 기록 없음) |  | 현장 조정 | 현장 상황에 따라 위치·고정·길이를 유연하게 조정. 강제 끼움/기판 홀 확대는 하지 않음 | CAD 적용/재료 후보 | 5 | PHOTO_BASED_SPEAKER_CONE_138; STANDARD_SPEAKER_GRILLE_138; PHOTO_BASED_SPEAKER_CONE_182; STANDARD_SPEAKER_GRILLE_182 | https://www.coupang.com/vp/products/1606481616?vendorItemId=83242018534&sourceType=CART | 수량 셀과 상품명 묶음 수량을 임의 곱셈하지 않음
26 | P1-026 | 1차 | 30 | 배터리 모니터링 | 아두이노 전압 측정 0~25V 전압 센서 모듈 | 1 |  | 구매 기록 |  | 측정 불필요 | 도구·소모품·예비/외부 사용품은 CAD에 강제 장착하지 않음 | 미장착·외부 사용·소모품 | 0 |  | https://www.coupang.com/vp/products/6473033109 | 수량 셀과 상품명 묶음 수량을 임의 곱셈하지 않음
27 | P1-027 | 1차 | 31 | 전원 설계 | 5개 Type-C MT3608 DC-DC 가변 승압 모듈 2A 스텝업 컨버터 | 1 |  | 구매 기록 |  | 측정 불필요 | P2-R22 190W 승압기를 현재 배치에 사용. MT3608 전부 장착할 필요 없음 | 미사용 예비 | 0 |  | https://www.coupang.com/vp/products/9640646849?itemId=28805622658&vendorItemId=95740820409 | 수량 셀과 상품명 묶음 수량을 임의 곱셈하지 않음
28 | P1-028 | 1차 | 32 | 통신 부품 | 에즈윈 인텔 AX210 Wi-Fi 6E Kit 무선랜카드 | 1 |  | 구매 기록 |  | 측정 불필요 | 도구·소모품·예비/외부 사용품은 CAD에 강제 장착하지 않음 | 미장착·외부 사용·소모품 | 0 |  | https://www.coupang.com/vp/products/8996103050?itemId=26357379570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 | 수량 셀과 상품명 묶음 수량을 임의 곱셈하지 않음
29 | P1-029 | 1차 | 33 | 메인 전원 스위치 | 12V 20A LED 원형 로커 스위치 3핀 차량·선박 겸용 2pcs | 1 | 12 | 근사 실측 | 몸통 Ø≈20; 테두리 Ø≈27; 전체 34.2 | 조건부 확인 | 5T 자투리에 Ø20 시험 구멍을 만들어 걸림턱·끼움 확인 후 본판에 전사 | CAD 적용/재료 후보 | 1 | PHOTO_BASED_MAIN_ROCKER | https://www.coupang.com/vp/products/9662908766?itemId=28888055885&vendorItemId=95820726117 | 수량 셀과 상품명 묶음 수량을 임의 곱셈하지 않음
30 | P2-R20 | 2차 | 20 | 배터리 충전기 | 이오전자 EO-1212 12V 1.2A 연축전지 자동충전기 | 1.0 |  | 구매 기록 |  | 측정 불필요 | 도구·소모품·예비/외부 사용품은 CAD에 강제 장착하지 않음 | 미장착·외부 사용·소모품 | 0 |  | https://www.coupang.com/vp/products/5469618401 | 수량 셀과 상품명 묶음 수량을 임의 곱셈하지 않음
31 | P2-R21 | 2차 | 21 | 커넥터 | JST-PH 6핀 케이블 2.0mm 피치 같은면 1대N(30cm ×4) | 8.0 | 4 | 상품명 | 길이 300; 피치 2.0; 6핀 | 현장 조정 | 핀 순서·같은면 여부를 실물 확인하고 당기지 않는 경로로 정리 | CAD 적용/재료 후보 | 206 | DRAWING_BASED_MOTOR_PH6_L; DRAWING_BASED_MOTOR_PH6_R; STANDARD_PLUG_HUB_USB0_SHELL; STANDARD_PLUG_HUB_USB0_TONGUE | https://www.coupang.com/vp/products/9303101206?itemId=27560476026 | 수량 셀과 상품명 묶음 수량을 임의 곱셈하지 않음
32 | P2-R22 | 2차 | 22 | 전원 설계 | 12V→19V DC 승압 컨버터 190W | 1.0 | 8 | 실측 | 75 × 75 × 31 | 현장 조정 | 방열·배선 여유를 남기고 고정홀만 실물 전사 | CAD 적용/재료 후보 | 1 | PHOTO_BASED_BOOST_190W | https://www.coupang.com/vp/products/7330179288?itemId=18817465936 | 수량 셀과 상품명 묶음 수량을 임의 곱셈하지 않음
33 | P2-R23 | 2차 | 23 | Jetson 전원 커넥터 | [Switchcraft Inc.] 760K | 2.0 |  | 이전 CAD/상품 자료 (실측 기록 없음) |  | 현장 조정 | 현장 상황에 따라 위치·고정·길이를 유연하게 조정. 강제 끼움/기판 홀 확대는 하지 않음 | CAD 적용/재료 후보 | 4 | DRAWING_BASED_760K_BARREL; DRAWING_BASED_760K_HANDLE; PHOTO_BASED_760K_RING; DRAWING_BASED_760K_NECK | https://www.devicemart.co.kr/goods/view?no=9189067&utm_source=chatgpt.com | 수량 셀과 상품명 묶음 수량을 임의 곱셈하지 않음
34 | P2-R24 | 2차 | 24 | 리미트 스위치 단자 | [TE Connectivity AMP Connectors] 2-520181-2 | 24.0 |  | 이전 CAD/상품 자료 (실측 기록 없음) |  | 현장 조정 | 현장 상황에 따라 위치·고정·길이를 유연하게 조정. 강제 끼움/기판 홀 확대는 하지 않음 | CAD 적용/재료 후보 | 8 | OFFICIAL_TE187_FRONT_0; OFFICIAL_TE187_FRONT_1; OFFICIAL_TE187_REAR_0; OFFICIAL_TE187_REAR_1 | https://www.devicemart.co.kr/goods/view?no=10570974&utm_source=chatgpt.com | 수량 셀과 상품명 묶음 수량을 임의 곱셈하지 않음
35 | P2-R25 | 2차 | 25 | - | [SEENGREAT] 열화상 카메라 모듈 IR MLX90640 [220565] | 1.0 |  | 이전 CAD/상품 자료 (실측 기록 없음) |  | 현장 조정 | 현장 상황에 따라 위치·고정·길이를 유연하게 조정. 강제 끼움/기판 홀 확대는 하지 않음 | CAD 적용/재료 후보 | 215 | OFFICIAL_THERMAL_0000_Solid; OFFICIAL_THERMAL_0001_Solid; OFFICIAL_THERMAL_0002_Solid; OFFICIAL_THERMAL_0003_Solid | https://www.devicemart.co.kr/goods/view?no=15356287 | 수량 셀과 상품명 묶음 수량을 임의 곱셈하지 않음
36 | P2-R26 | 2차 | 26 | 퓨즈 홀더 - FHAC0002LXN | [Littelfuse Inc.] FHAC0002LXN | 2.0 |  | 이전 CAD/상품 자료 (실측 기록 없음) |  | 현장 조정 | 현장 상황에 따라 위치·고정·길이를 유연하게 조정. 강제 끼움/기판 홀 확대는 하지 않음 | CAD 적용/재료 후보 | 28 | DRAWING_BASED_FHAC_BODY_0; STANDARD_FHAC_CONTACT_0_19; STANDARD_FHAC_CONTACT_0_29; DRAWING_BASED_FHAC_CAP_0 | https://www.devicemart.co.kr/goods/view?no=8994638 | 수량 셀과 상품명 묶음 수량을 임의 곱셈하지 않음
37 | P2-R27 | 2차 | 27 | 멀티미터(전기 측정) | [UNI-T] 디지털 클램프(후쿠메타)미터 UT210E | 1.0 |  | 구매 기록 |  | 측정 불필요 | 도구·소모품·예비/외부 사용품은 CAD에 강제 장착하지 않음 | 미장착·외부 사용·소모품 | 0 |  | https://www.devicemart.co.kr/goods/view?no=6500258&utm_source=chatgpt.com | 수량 셀과 상품명 묶음 수량을 임의 곱셈하지 않음
38 | P2-R28 | 2차 | 28 | 배터리용 암 압착단자(+) | 아트얼스 PG 압착 터미널 절연 단자 FDFD 5.5-250 전기 전선 케이블 배선 평단자 6.3mm 옐로우 PG24A | 5.0 |  | 구매 기록 |  | 측정 불필요 | 도구·소모품·예비/외부 사용품은 CAD에 강제 장착하지 않음 | 미장착·외부 사용·소모품 | 0 |  | https://www.coupang.com/vp/products/8820393437?vendorItemId=95722267821&sourceType=CART | 수량 셀과 상품명 묶음 수량을 임의 곱셈하지 않음
39 | P2-R29 | 2차 | 29 | 동일규격 / 6.3mm 평단자 / 1개 단가 검색결과 기준 | PG 압착 터미널 절연 단자 FDFD 2-250 전기 전선 케이블 배선 평단자 6.3mm 블루 PG15A | 5.0 |  | 구매 기록 |  | 측정 불필요 | 도구·소모품·예비/외부 사용품은 CAD에 강제 장착하지 않음 | 미장착·외부 사용·소모품 | 0 |  | https://www.11st.co.kr/products/8304614495?catalog_no=503168967&lowest_yn=Y | 수량 셀과 상품명 묶음 수량을 임의 곱셈하지 않음
40 | P2-R30 | 2차 | 30 | 서보모터(카메라 움직임) | [DFRobot] SER0063 | 2.0 | 3 | 근사 실측 | ≈55 × ≈20 × ≈47–48; 원본 CAD 55 × 20.5 × 47.38 | 필수 확인 | 모터 본체 재측정 불필요. 사용할 혼의 홀 간격·지름·두께·끼운 높이만 필요 | CAD 적용/재료 후보 | 2 | USER_SER0063_PAN; USER_SER0063_TILT | https://naver.me/xSBUqx9l | 수량 셀과 상품명 묶음 수량을 임의 곱셈하지 않음
41 | P2-R31 | 2차 | 31 | 릴레이 보호 다이오드 | (10개/세트) 1N4007 정류 다이오드 - 1A 1000V 고전압 DO-41 패키지 - 역전류 방지 전자부품 | 1.0 |  | 이전 CAD/상품 자료 (실측 기록 없음) |  | 현장 조정 | 현장 상황에 따라 위치·고정·길이를 유연하게 조정. 강제 끼움/기판 홀 확대는 하지 않음 | CAD 적용/재료 후보 | 1 | DRAWING_BASED_1N4007 | https://www.coupang.com/vp/products/9217071237?utm_source=chatgpt.com | 수량 셀과 상품명 묶음 수량을 임의 곱셈하지 않음
42 | P2-R32 | 2차 | 32 | 절연단자 압착기 | IWISS 터미널압착기 PG단자 압착공구 HS-30J | 1.0 |  | 구매 기록 |  | 측정 불필요 | 도구·소모품·예비/외부 사용품은 CAD에 강제 장착하지 않음 | 미장착·외부 사용·소모품 | 0 |  | https://www.coupang.com/vp/products/7151834751?utm_source=chatgpt.com | 수량 셀과 상품명 묶음 수량을 임의 곱셈하지 않음
43 | P2-R33 | 2차 | 33 | 와이어 스트리퍼 | 엔지니어 스트리퍼 PAW-31 전선 와이어 피복 탈피 | 1.0 |  | 구매 기록 |  | 측정 불필요 | 도구·소모품·예비/외부 사용품은 CAD에 강제 장착하지 않음 | 미장착·외부 사용·소모품 | 0 |  | https://www.devicemart.co.kr/goods/view?no=15095700&utm_source=chatgpt.com | 수량 셀과 상품명 묶음 수량을 임의 곱셈하지 않음
44 | P2-R34 | 2차 | 34 | 인두기 | [하코 HAKKO] 온도조절인두기 FX-600 (T18-B 인두팁 포함) | 1.0 |  | 구매 기록 |  | 측정 불필요 | 도구·소모품·예비/외부 사용품은 CAD에 강제 장착하지 않음 | 미장착·외부 사용·소모품 | 0 |  | https://www.coupang.com/vp/products/211942729?utm_source=chatgpt.com | 수량 셀과 상품명 묶음 수량을 임의 곱셈하지 않음
45 | P2-R35 | 2차 | 35 | 납 | [Singapore Asahi] 스프링 무연납 SCS7(P3.5) - 0.8mm (10g/1.8M) | 4.0 |  | 구매 기록 |  | 측정 불필요 | 도구·소모품·예비/외부 사용품은 CAD에 강제 장착하지 않음 | 미장착·외부 사용·소모품 | 0 |  | https://www.devicemart.co.kr/goods/view?no=1089518&utm_source=chatgpt.com | 수량 셀과 상품명 묶음 수량을 임의 곱셈하지 않음
46 | P2-R36 | 2차 | 36 | 인두 거치대 | 스프링형 인두기 거치대 스텐드 납땜기 철제 받침대 걸이 | 1.0 |  | 구매 기록 |  | 측정 불필요 | 도구·소모품·예비/외부 사용품은 CAD에 강제 장착하지 않음 | 미장착·외부 사용·소모품 | 0 |  | https://www.coupang.com/vp/products/9545942672?utm_source=chatgpt.com | 수량 셀과 상품명 묶음 수량을 임의 곱셈하지 않음
47 | P2-R37 | 2차 | 37 | 유사사양 / 127pcs 열수축튜브 세트 | 열 선보호 수축튜브 127pcs 블랙 세트 | 1.0 |  | 구매 기록 |  | 측정 불필요 | 도구·소모품·예비/외부 사용품은 CAD에 강제 장착하지 않음 | 미장착·외부 사용·소모품 | 0 |  | https://catalog.11st.co.kr/pc/320052339?poc=pc&sortCds=DLV_INCLUDE | 수량 셀과 상품명 묶음 수량을 임의 곱셈하지 않음
48 | P2-R38 | 2차 | 38 | 히트건 | 홈플래닛 1800W 열풍기 히팅건 | 1.0 |  | 구매 기록 |  | 측정 불필요 | 도구·소모품·예비/외부 사용품은 CAD에 강제 장착하지 않음 | 미장착·외부 사용·소모품 | 0 |  | https://www.coupang.com/vp/products/7061213448?utm_source=chatgpt.com | 수량 셀과 상품명 묶음 수량을 임의 곱셈하지 않음
49 | P2-R39 | 2차 | 39 | 볼트/너트 세트 | [로보티즈] 볼트너트 세트 BNS-30 | 1.0 |  | 구매 기록 |  | 현장 조정 | BNS-30 탭핑 나사와 M2/M2.5 기계나사를 구분. 키트라는 이유로 모든 CAD 체결품을 보유했다고 보지 않음 | 미장착·외부 사용·소모품 | 0 |  | https://www.devicemart.co.kr/goods/view?no=1112078 | 수량 셀과 상품명 묶음 수량을 임의 곱셈하지 않음
50 | P2-R40 | 2차 | 40 | 케이블타이 | 얇은 케이블타이 100pcs 블랙/화이트 thin cable tie | 1.0 |  | 구매 기록 |  | 측정 불필요 | 도구·소모품·예비/외부 사용품은 CAD에 강제 장착하지 않음 | 미장착·외부 사용·소모품 | 0 |  | https://www.coupang.com/vp/products/4388722297?itemId=5198845198&vendorItemId=72508029620 | 수량 셀과 상품명 묶음 수량을 임의 곱셈하지 않음
51 | P2-R41 | 2차 | 41 | 테이프 | 쿠말 접착 초강력 벨크로 테이프 갈고리면 20mm x 5m + 부착면 20mm x 5m 세트, 화이트, 3세트 | 1.0 |  | 구매 기록 |  | 측정 불필요 | 도구·소모품·예비/외부 사용품은 CAD에 강제 장착하지 않음 | 미장착·외부 사용·소모품 | 0 |  | https://www.coupang.com/vp/products/8610527698 | 수량 셀과 상품명 묶음 수량을 임의 곱셈하지 않음
52 | P2-R42 | 2차 | 42 | USB 3.0 유전원 허브 4포트 | 넥스트유 USB 3.0 4포트 유전원 허브 케이블일체형 NEXT 505UHP + 어댑터 | 1.0 |  | 이전 CAD/상품 자료 (실측 기록 없음) | 101 × 41 × 25 (이전 상품 근거) | 현장 조정 | 현장 상황에 따라 위치·고정·길이를 유연하게 조정. 강제 끼움/기판 홀 확대는 하지 않음 | CAD 적용/재료 후보 | 5 | PHOTO_BASED_NEXT505UHP; APPROX_HUB_USB_A_0; APPROX_HUB_USB_A_1; APPROX_HUB_USB_A_2 | https://www.coupang.com/vp/products/73214278?vendorItemId=3600609378&sourceType=CART | 수량 셀과 상품명 묶음 수량을 임의 곱셈하지 않음
53 | P2-R43 | 2차 | 43 | USB A to C 데이터 케이블 1M | coms ABFC100 USB A to C타입 케이블 1M 블랙 데이터 충전 | 2.0 |  | 이전 CAD/상품 자료 (실측 기록 없음) |  | 현장 조정 | 현장 상황에 따라 위치·고정·길이를 유연하게 조정. 강제 끼움/기판 홀 확대는 하지 않음 | CAD 적용/재료 후보 | 17 | STANDARD_PLUG_ESP32_USB_SHELL; STANDARD_PLUG_ESP32_USB_TONGUE; STANDARD_PLUG_ESP32_USB_CONTACT_0; STANDARD_PLUG_ESP32_USB_CONTACT_1 | https://www.coupang.com/vp/products/6322035507 | 수량 셀과 상품명 묶음 수량을 임의 곱셈하지 않음
54 | P2-R44 | 2차 | 44 | Micro USB 데이터 케이블 1M | 개발용 마이크로 USB 케이블 | 2.0 |  | 구매 기록 |  | 측정 불필요 | 도구·소모품·예비/외부 사용품은 CAD에 강제 장착하지 않음 | 미장착·외부 사용·소모품 | 0 |  | https://www.coupang.com/vp/products/7206616633 | 수량 셀과 상품명 묶음 수량을 임의 곱셈하지 않음
55 | P2-R45 | 2차 | 45 | DP to HDMI 케이블/어댑터 | DP to HDMI 2.1 8K@60Hz 케이블 3m | 1.0 |  | 구매 기록 |  | 측정 불필요 | 도구·소모품·예비/외부 사용품은 CAD에 강제 장착하지 않음 | 미장착·외부 사용·소모품 | 0 |  | https://www.coupang.com/vp/products/6211015984 | 수량 셀과 상품명 묶음 수량을 임의 곱셈하지 않음
56 | P2-R46 | 2차 | 46 | CAT.6 랜선 3m | 랜스타 UTP CAT.6 다이렉트 랜 케이블 x 3 | 2.0 |  | 구매 기록 |  | 측정 불필요 | 도구·소모품·예비/외부 사용품은 CAD에 강제 장착하지 않음 | 미장착·외부 사용·소모품 | 0 |  | https://www.coupang.com/vp/products/70339768 | 수량 셀과 상품명 묶음 수량을 임의 곱셈하지 않음
57 | P2-R47 | 2차 | 47 | 3M 절연테이프 | [YM] 3M 전기 절연 비닐테이프 1711 | 2.0 |  | 구매 기록 |  | 측정 불필요 | 도구·소모품·예비/외부 사용품은 CAD에 강제 장착하지 않음 | 미장착·외부 사용·소모품 | 0 |  | https://www.coupang.com/vp/products/1444015226?itemId=2370652604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 | 수량 셀과 상품명 묶음 수량을 임의 곱셈하지 않음
58 | P2-R48 | 2차 | 48 | 납땜 플럭스펜 | 납땜 플럭스 펜 10ml 태양 전지 공정 무세척 DIY 케스터 용접, 플럭스펜 GD24062 3개 | 1.0 |  | 구매 기록 |  | 측정 불필요 | 도구·소모품·예비/외부 사용품은 CAD에 강제 장착하지 않음 | 미장착·외부 사용·소모품 | 0 |  | https://www.coupang.com/vp/products/9344303358?utm_source=chatgpt.com | 수량 셀과 상품명 묶음 수량을 임의 곱셈하지 않음
59 | P2-R49 | 2차 | 49 | 솔더윅/납 제거선 | 솔더윅 솔더위크 납땜 제거 흡입기 디솔더링, 2개 | 1.0 |  | 구매 기록 |  | 측정 불필요 | 도구·소모품·예비/외부 사용품은 CAD에 강제 장착하지 않음 | 미장착·외부 사용·소모품 | 0 |  | https://www.coupang.com/vp/products/8316119006?utm_source=chatgpt.com | 수량 셀과 상품명 묶음 수량을 임의 곱셈하지 않음
60 | P2-R50 | 2차 | 50 | 동일규격 / 20cm / 암암·암수·수수 3종 점퍼케이블 | JK 브레드보드 점퍼선 점퍼 케이블 40P 암컷 숫컷 아두이노 40가닥 DIY 와이어 | 1.0 |  | 이전 CAD/상품 자료 (실측 기록 없음) |  | 현장 조정 | 현장 상황에 따라 위치·고정·길이를 유연하게 조정. 강제 끼움/기판 홀 확대는 하지 않음 | CAD 적용/재료 후보 | 204 | STANDARD_PLUG_HUB_USB0_SHELL; STANDARD_PLUG_HUB_USB0_TONGUE; STANDARD_PLUG_HUB_USB0_CONTACT_0; STANDARD_PLUG_HUB_USB0_CONTACT_1 | https://www.coupang.com/vp/products/9482860709?itemId=28235768186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 | 수량 셀과 상품명 묶음 수량을 임의 곱셈하지 않음
61 | P2-R51 | 2차 | 51 | 포맥스판 / 5T / 600×900mm / 백색 / 구조 장착판 가공용 | 포멕스판 (600mmx900mm)5T 백색/포멕스&포맥스 | 2.0 |  | 이전 CAD/상품 자료 (실측 기록 없음) |  | 필수 확인 | 네 점 모두 맞으면 새로 전부 측정할 필요 없음. 다르면 해당 홀 중심 좌표만 측정 | CAD 적용/재료 후보 | 111 | CUSTOM_BOTTOM_PLATE; CUSTOM_BATTERY_PLATE; CUSTOM_CHASSIS_PAD_0_0; CUSTOM_CHASSIS_PAD_0_1 | https://www.coupang.com/vp/products/7354908604?utm_source=chatgpt.com | 수량 셀과 상품명 묶음 수량을 임의 곱셈하지 않음
62 | P2-R52 | 2차 | 52 | 동일규격 / M4 / 1m / 철 전산볼트 / 색상·도금 차이 가능 | [새한볼트] 전산볼트(노란도금) M4-1M | 5.0 |  | 이전 CAD/상품 자료 (실측 기록 없음) |  | 현장 조정 | 현장 상황에 따라 위치·고정·길이를 유연하게 조정. 강제 끼움/기판 홀 확대는 하지 않음 | CAD 적용/재료 후보 | 14 | DRAWING_BASED_M4_ROD_0; DRAWING_BASED_M4_ROD_1; DRAWING_BASED_M4_ROD_2; DRAWING_BASED_M4_ROD_3 | https://www.devicemart.co.kr/goods/view?no=1330780 | 수량 셀과 상품명 묶음 수량을 임의 곱셈하지 않음
63 | P2-R53 | 2차 | 53 | M4 너트/와셔 포함 체결 세트 / SUS304 / M3·M4·M5 혼합 / 2세트 | 스텐 둥근 냄비 머리 볼트 너트 와셔 세트 600SET SUS304 M3 M4 M5 | 1.0 |  | 이전 CAD/상품 자료 (실측 기록 없음) |  | 현장 조정 | 현장 상황에 따라 위치·고정·길이를 유연하게 조정. 강제 끼움/기판 홀 확대는 하지 않음 | CAD 적용/재료 후보 | 492 | M4_CHASSIS_0; M4_CHASSIS_W_0; M4_CHASSIS_N_0; M4_CHASSIS_1 | https://www.coupang.com/vp/products/7508022659?utm_source=chatgpt.com | 수량 셀과 상품명 묶음 수량을 임의 곱셈하지 않음
64 | P2-R54 | 2차 | 54 | ㄱ자/L자 브라켓 / 소형 / 20개 / 센서·소형 판재 고정용 | 네이쳐툴 ㄱ자 선반 꺽쇠 코너 기억자 코너철 소형, 소형, 20개 | 1.0 | 6 | 사용자 전사 규격 | 20 × 24 × 24; 소형 실물 보유 불확실 | 조건부 확인 | 고정부는 보유 중형으로 재배치 가능. 회전부에 쓸 때만 두께·돌기·체결 여유 확인 | 규격 참고 / 소형 실물 미확인 | 12 | APPROX_SMALL_L_0_23_LEFT; APPROX_SMALL_L_0_23_RIGHT; APPROX_SMALL_L_0_245_LEFT; APPROX_SMALL_L_0_245_RIGHT | https://www.coupang.com/vp/products/9180532021?itemId=27052882342&vendorItemId=94021286033 | 수량 셀과 상품명 묶음 수량을 임의 곱셈하지 않음
65 | P2-R55 | 2차 | 55 | ㄱ자/L자 브라켓 / 중형 / 20개 / 상판·라이다 타워·보강용 | 네이쳐툴 ㄱ자 선반 꺽쇠 코너 기억자 코너철 소형, 중형, 20개 | 1.0 | 7 | 실측 | 30 × 25 × 25 | 현장 조정 | 고정된 판의 홀은 실물 꺽쇠 전사. 카메라 회전부에 채택하면 회전 간격 확인 | CAD 적용/재료 후보 | 4 | APPROX_MEDIUM_L_0; APPROX_MEDIUM_L_1; APPROX_MEDIUM_L_2; APPROX_MEDIUM_L_3 | https://www.coupang.com/vp/products/9180532021?itemId=27073271830&vendorItemId=94033298242 | 수량 셀과 상품명 묶음 수량을 임의 곱셈하지 않음
66 | P2-R56 | 2차 | 56 | M3 PCB 스페이서 세트 / 260P / 보드 절연·고정용 / 2세트 | 260P M3 나일론 스페이서 너트 세트 - 육각 기판 고정용 나사 키트 - PCB 조립용 | 1.0 | 5 | 미실측 | 설치할 길이만 선택 | 현장 조정 | 부품을 올린 뒤 필요한 몸통 길이·나사 체결 길이·절연 간격 선택 | CAD 적용/재료 후보 | 492 | M4_CHASSIS_0; M4_CHASSIS_W_0; M4_CHASSIS_N_0; M4_CHASSIS_1 | https://www.coupang.com/vp/products/8812110205?utm_source=chatgpt.com | 수량 셀과 상품명 묶음 수량을 임의 곱셈하지 않음
67 | P2-R57 | 2차 | 57 | 동일제품 / 25mm×0.9m / 흑색 / 배터리·부품 고정용 / 3개 기준 | 벨크로 찍찍이 세트 25mm x 0.9m 흑색 다용도 고정 스트랩 1개입 커머스픽101 | 1.0 |  | 이전 CAD/상품 자료 (실측 기록 없음) |  | 현장 조정 | 현장 상황에 따라 위치·고정·길이를 유연하게 조정. 강제 끼움/기판 홀 확대는 하지 않음 | CAD 적용/재료 후보 | 4 | CUSTOM_BATTERY_STRAP_0; PHOTO_BASED_STRAP_BUCKLE_0; CUSTOM_BATTERY_STRAP_1; PHOTO_BASED_STRAP_BUCKLE_1 | coupang.com/vp/products/8529109797?itemId=24948796869&vendorItemId=75134934386&q=벨크로%20찍찍이%20세트%2025mm%20x%200.9m%20흑색%20다용도%20고정%20스트랩%201개입%20커머스픽101&searchId=e90227007915826&sourceType=search&itemsCount=60&searchRank=4&rank=4&traceId=mu1fj2qp | 수량 셀과 상품명 묶음 수량을 임의 곱셈하지 않음
68 | P2-R58 | 2차 | 58 | 포맥스 커터/아크릴 커터 / 기본칼날 3p + 추가칼날 10p / 2세트 | 모나코올리브 아크릴 커터 컷팅 칼 + 기본칼날 3p + 추가칼날 10p 세트, 2세트 | 1.0 |  | 구매 기록 |  | 측정 불필요 | 도구·소모품·예비/외부 사용품은 CAD에 강제 장착하지 않음 | 미장착·외부 사용·소모품 | 0 |  | https://www.coupang.com/vp/products/8628610238?itemId=25035550889&vendorItemId=92173489231 | 수량 셀과 상품명 묶음 수량을 임의 곱셈하지 않음
69 | P2-R59 | 2차 | 59 | 스탠맨 21V 무선충전 해머전동드릴 공구세트 / ST-6000 / 1세트 | 스탠맨 ST-6000 (2.0Ah, 배터리 1개) | 1.0 |  | 구매 기록 |  | 측정 불필요 | 도구·소모품·예비/외부 사용품은 CAD에 강제 장착하지 않음 | 미장착·외부 사용·소모품 | 0 |  | https://www.coupang.com/vp/products/7449959434?itemId=19392413453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 | 수량 셀과 상품명 묶음 수량을 임의 곱셈하지 않음
70 | P2-R60 | 2차 | 60 | HSS 메탈 드릴비트 / 2~8mm / 6종 / 2607010529 / 2세트 | 보쉬 PRO HSS 메탈 드릴비트 6종 세트 2~8mm / 2607010529., 2세트 | 1.0 |  | 구매 기록 |  | 측정 불필요 | 도구·소모품·예비/외부 사용품은 CAD에 강제 장착하지 않음 | 미장착·외부 사용·소모품 | 0 |  | https://www.coupang.com/vp/products/8736392839?vendorItemId=92497701254&sourceType=CART | 수량 셀과 상품명 묶음 수량을 임의 곱셈하지 않음
71 | P2-R61 | 2차 | 61 | Mini Hacksaw DL353312 / 300mm·12인치 / Bi-metal 톱날 / 2개 | 델리툴즈 경량 톱 쇠톱 미니 12인치 줄톱 톱대 | 1.0 |  | 구매 기록 |  | 측정 불필요 | 도구·소모품·예비/외부 사용품은 CAD에 강제 장착하지 않음 | 미장착·외부 사용·소모품 | 0 |  | https://www.coupang.com/vp/products/8975914021?vendorItemId=93275665490&sourceType=CART | 수량 셀과 상품명 묶음 수량을 임의 곱셈하지 않음
72 | P2-R62 | 2차 | 62 | PH1·PH2·일자 5mm·6.5mm / 4PCS / DWHT65101 | [디월트] 스크류드라이버 4 PCS 세트 DWHT65101 | 1.0 |  | 구매 기록 |  | 측정 불필요 | 도구·소모품·예비/외부 사용품은 CAD에 강제 장착하지 않음 | 미장착·외부 사용·소모품 | 0 |  | https://www.devicemart.co.kr/goods/view?no=14761245&utm_source=chatgpt.com | 수량 셀과 상품명 묶음 수량을 임의 곱셈하지 않음
73 | P2-R63 | 2차 | 63 | 니퍼 / 150mm / BST-13203 / 1개 | BESTIR 니퍼 150mm BST-13203, 1개 | 1.0 |  | 구매 기록 |  | 측정 불필요 | 도구·소모품·예비/외부 사용품은 CAD에 강제 장착하지 않음 | 미장착·외부 사용·소모품 | 0 |  | https://www.coupang.com/vp/products/8586101289 | 수량 셀과 상품명 묶음 수량을 임의 곱셈하지 않음
74 | P2-R64 | 2차 | 64 | 니들 롱노즈 플라이어 / STHT84096-8 / 5인치급 / 1개 | STANLEY 니들 롱로즈 플라이어 스탠리STHT84096-8 롱로우즈 롱노즈플라이어 롱로즈 | 1.0 |  | 구매 기록 |  | 측정 불필요 | 도구·소모품·예비/외부 사용품은 CAD에 강제 장착하지 않음 | 미장착·외부 사용·소모품 | 0 |  | https://www.coupang.com/vp/products/4701063165 | 수량 셀과 상품명 묶음 수량을 임의 곱셈하지 않음
75 | P2-R65 | 2차 | 65 | 정밀 줄 세트 / 10종 / 2세트 | G.L.S 정밀 줄 세트 10종 줄세트 | 1.0 |  | 구매 기록 |  | 측정 불필요 | 도구·소모품·예비/외부 사용품은 CAD에 강제 장착하지 않음 | 미장착·외부 사용·소모품 | 0 |  | https://www.coupang.com/vp/products/8908142363 | 수량 셀과 상품명 묶음 수량을 임의 곱셈하지 않음
76 | P2-R66 | 2차 | 66 | 240·320·400·600·800·1000·1200·1500·2000 grit / 2세트 | 샌드페이퍼 240/320/400/600/800/1000/1200/1500/2000 그릿 사포 물/건식 샌딩페이퍼 연마재 | 1.0 |  | 구매 기록 |  | 측정 불필요 | 도구·소모품·예비/외부 사용품은 CAD에 강제 장착하지 않음 | 미장착·외부 사용·소모품 | 0 |  | https://www.coupang.com/vp/products/9473650656?vendorItemId=95316829435&sourceType=CART | 수량 셀과 상품명 묶음 수량을 임의 곱셈하지 않음
77 | P2-R67 | 2차 | 67 | C형/G형 클램프 / 4인치 / 최대 105mm / 2개입 | C형 클램프 4인치 105mm G형 목공용, 2개 | 1.0 |  | 구매 기록 |  | 측정 불필요 | 도구·소모품·예비/외부 사용품은 CAD에 강제 장착하지 않음 | 미장착·외부 사용·소모품 | 0 |  | https://www.coupang.com/vp/products/8261073812 | 수량 셀과 상품명 묶음 수량을 임의 곱셈하지 않음
78 | P2-R68 | 2차 | 68 | 투명 방풍 고글/보안경 | 엠믹스 김서림방지 고글 보안경 작업용 보호안경 MX-B1 | 1.0 |  | 구매 기록 |  | 측정 불필요 | 도구·소모품·예비/외부 사용품은 CAD에 강제 장착하지 않음 | 미장착·외부 사용·소모품 | 0 |  | https://www.coupang.com/vp/products/8489843090?itemId=24572392237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 | 수량 셀과 상품명 묶음 수량을 임의 곱셈하지 않음
79 | P2-R69 | 2차 | 69 | Melange Gray × L × 3개 | 쓰리엠 컴포트 그립 터치 양손세트 | 1.0 |  | 구매 기록 |  | 측정 불필요 | 도구·소모품·예비/외부 사용품은 CAD에 강제 장착하지 않음 | 미장착·외부 사용·소모품 | 0 |  | https://www.coupang.com/vp/products/8593053393?utm_source=chatgpt.com | 수량 셀과 상품명 묶음 수량을 임의 곱셈하지 않음
80 | P2-R70 | 2차 | 70 | 스텐/철제 직자 / 60cm / 1개 | 철자 스틸자 스텐자 직자 60CM 철제자 커팅자 | 1.0 |  | 구매 기록 |  | 측정 불필요 | 도구·소모품·예비/외부 사용품은 CAD에 강제 장착하지 않음 | 미장착·외부 사용·소모품 | 0 |  | https://www.coupang.com/vp/products/8322949454?itemId=24024398579&vendorItemId=91158907641 | 수량 셀과 상품명 묶음 수량을 임의 곱셈하지 않음
81 | P2-R71 | 2차 | 71 | 미니 양구 스패너 / 3·4·5·6·7·8·10·11·13mm / 9종 / 1세트 | 스마토 미니 양구 스패너 9종 세트 SM-MOW9P, 1세트 | 1.0 |  | 구매 기록 |  | 측정 불필요 | 도구·소모품·예비/외부 사용품은 CAD에 강제 장착하지 않음 | 미장착·외부 사용·소모품 | 0 |  | https://www.coupang.com/vp/products/4609884713 | 수량 셀과 상품명 묶음 수량을 임의 곱셈하지 않음
82 | P2-R72 | 2차 | 72 | 볼 L형 육각렌치 / mm 규격 / 1.5·2·2.5·3·4·5·6·8·10mm / 9pcs | 일제 육각렌치 볼 L 엘렌치 세트 미리 mm 렌찌 9pcs | 1.0 |  | 구매 기록 |  | 측정 불필요 | 도구·소모품·예비/외부 사용품은 CAD에 강제 장착하지 않음 | 미장착·외부 사용·소모품 | 0 |  | https://www.coupang.com/vp/products/7567504928 | 수량 셀과 상품명 묶음 수량을 임의 곱셈하지 않음
83 | P2-R73 | 2차 | 73 | ESC-4S / HSS / 4~12·4~20·4~32mm / 2세트 | [이엑스파워] 스텝드릴 세트 ESC-4S | 1.0 |  | 구매 기록 |  | 측정 불필요 | 도구·소모품·예비/외부 사용품은 CAD에 강제 장착하지 않음 | 미장착·외부 사용·소모품 | 0 |  | https://www.devicemart.co.kr/goods/view?no=15865788 | 수량 셀과 상품명 묶음 수량을 임의 곱셈하지 않음
84 | P2-R74 | 2차 | 74 | 400핀 Half Size Breadboard / SZH-BBAD-005 / 5개 | [SMG] 브레드보드 400핀 Half Size Breadboard [SZH-BBAD-005] | 5.0 |  | 구매 기록 |  | 측정 불필요 | 도구·소모품·예비/외부 사용품은 CAD에 강제 장착하지 않음 | 미장착·외부 사용·소모품 | 0 |  | https://www.devicemart.co.kr/goods/view?no=1328148 | 수량 셀과 상품명 묶음 수량을 임의 곱셈하지 않음
85 | P2-R75 | 2차 | 75 | 스텐 나일론너트 M4 × 1개 | 하나로볼트 스텐 나일론 너트 볼트 풀림방지 M3 M4 M5 M6 M8 M10 M12 M16 M20, 1개 | 100.0 |  | 이전 CAD/상품 자료 (실측 기록 없음) |  | 현장 조정 | 현장 상황에 따라 위치·고정·길이를 유연하게 조정. 강제 끼움/기판 홀 확대는 하지 않음 | CAD 적용/재료 후보 | 492 | M4_CHASSIS_0; M4_CHASSIS_W_0; M4_CHASSIS_N_0; M4_CHASSIS_1 | https://www.coupang.com/vp/products/8370981674?itemId=24189936695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 | 수량 셀과 상품명 묶음 수량을 임의 곱셈하지 않음
86 | P2-R76 | 2차 | 76 | 고밀도 EVA 방진패드 / 블랙 / 8cm × 8cm / 2P / 5세트 기준 | 고밀도 EVA 방진패드 충격흡수패드 | 3.0 |  | 이전 CAD/상품 자료 (실측 기록 없음) |  | 현장 조정 | 현장 상황에 따라 위치·고정·길이를 유연하게 조정. 강제 끼움/기판 홀 확대는 하지 않음 | CAD 적용/재료 후보 | 5 | BOOST_GROMMET_IN_POS; BOOST_GROMMET_IN_NEG; BOOST_GROMMET_OUT_POS; BOOST_GROMMET_OUT_NEG | https://www.coupang.com/vp/products/8593772969?vendorItemId=91685164013&sourceType=CART | 수량 셀과 상품명 묶음 수량을 임의 곱셈하지 않음
87 | P2-R77 | 2차 | 77 | 록타이트 222 / 저강도 / 5g / 3개 기준 | 록타이트 222 나사고정제 5g 저강도 볼트 너트 소형 나사고정제 나사풀림방지 | 2.0 |  | 구매 기록 |  | 측정 불필요 | 도구·소모품·예비/외부 사용품은 CAD에 강제 장착하지 않음 | 미장착·외부 사용·소모품 | 0 |  | https://www.coupang.com/vp/products/8188218348 | 수량 셀과 상품명 묶음 수량을 임의 곱셈하지 않음
88 | P2-R78 | 2차 | 78 | 아두이노 MG995 MG996용 서보모터 브라켓 | 아두이노 MG995 MG996용 서보모터 브라켓 METAL-BRACKET | 2.0 | 13 | 사진 근사 실측 | ㄷ자 64 × 55 × 25; 다른 프레임 58 × 37 × 25 | 조건부 확인 | 회전 지지부로 채택할 때만 안쪽 폭·두께·축홀/베어링 치수 필요 | 선택 재고 외곽 STEP / 본체 미장착 | 0 |  | https://www.coupang.com/vp/products/1346950788?utm_source=chatgpt.com | 수량 셀과 상품명 묶음 수량을 임의 곱셈하지 않음
89 | P2-R79 | 2차 | 79 | 입력 2, 출력 8, 모델명 SZH-CP003 | [SMG] 전원분배 단자대 / 터미널블럭 (입력2, 출력8)[SZH-CP003] | 1.0 | 1 | 실측 | 100 × 45 × 33; 입력 나사 ≈7.5; 출력 개구 ≈5.5–6 | 현장 조정 | 고정 위치는 실물 전사. 덮개 열림·절연 간격·단자 그룹은 결선 전에 확인 | CAD 적용/재료 후보 | 1 | PURCHASE_SZH_CP003_OUTLINE | https://www.devicemart.co.kr/goods/view?no=12498800&utm_source=chatgpt.com | 수량 셀과 상품명 묶음 수량을 임의 곱셈하지 않음
90 | P2-R80 | 2차 | 80 | 3핀 JR/Futaba 계열, 길이 30cm, 모델명 MAC-029 | [Yeahbot] 서보 연장 케이블 30cm [MAC-029] | 5.0 |  | 이전 CAD/상품 자료 (실측 기록 없음) |  | 현장 조정 | 현장 상황에 따라 위치·고정·길이를 유연하게 조정. 강제 끼움/기판 홀 확대는 하지 않음 | CAD 적용/재료 후보 | 204 | STANDARD_PLUG_HUB_USB0_SHELL; STANDARD_PLUG_HUB_USB0_TONGUE; STANDARD_PLUG_HUB_USB0_CONTACT_0; STANDARD_PLUG_HUB_USB0_CONTACT_1 | https://www.devicemart.co.kr/goods/view?no=15453298&utm_source=chatgpt.com | 수량 셀과 상품명 묶음 수량을 임의 곱셈하지 않음
91 | P2-R81 | 2차 | 81 | 전시 패널 | LED 라이트패널 실내용 벽걸이 엘이디광고패널 | 1.0 |  | 구매 기록 |  | 측정 불필요 | 도구·소모품·예비/외부 사용품은 CAD에 강제 장착하지 않음 | 미장착·외부 사용·소모품 | 0 |  | https://www.coupang.com/vp/products/9592149297?vendorItemId=95577353655&sourceType=CART | 수량 셀과 상품명 묶음 수량을 임의 곱셈하지 않음
92 | P2-R82 | 2차 | 82 | 음향장치 스피커 | [한국 정발] 에디파이어 PC-FI 데스크 파이 스튜디오 모니터 스피커 | 1.0 |  | 구매 기록 |  | 측정 불필요 | 도구·소모품·예비/외부 사용품은 CAD에 강제 장착하지 않음 | 미장착·외부 사용·소모품 | 0 |  | https://www.coupang.com/vp/products/9624937854?itemId=28743865093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 | 수량 셀과 상품명 묶음 수량을 임의 곱셈하지 않음
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

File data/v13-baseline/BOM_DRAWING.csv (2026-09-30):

ITEM | PART NAME | QTY | TYPE | SOURCE | DRAWING No. | NOTE
001 | Hiwonder tracked chassis | 1 | PURCHASED | MANUFACTURER_CAD / MANUFACTURER_DRAWING / REPAIRED_MANUFACTURER_CAD | A-001 / A-005 | CAD placement / envelope; actual mating features: VERIFY ON HARDWARE
002 | NVIDIA Jetson Orin Nano | 1 | PURCHASED | MANUFACTURER_CAD | A-001 / A-005 | CAD placement / envelope; actual mating features: VERIFY ON HARDWARE
003 | Logitech C920 | 1 | PURCHASED | COMMUNITY_CAD | A-001 / A-005 | CAD placement / envelope; actual mating features: VERIFY ON HARDWARE
004 | MLX90640 Thermal Camera HAT | 1 | PURCHASED | MANUFACTURER_CAD | A-001 / A-005 | CAD placement / envelope; actual mating features: VERIFY ON HARDWARE
005 | RPLIDAR A2M12 | 1 | PURCHASED | MANUFACTURER_DRAWING / PHOTO_ESTIMATE | A-001 / A-005 | CAD placement / envelope; actual mating features: VERIFY ON HARDWARE
006 | ESP32 DevKit 38-pin | 1 | PURCHASED | ADAPTED_COMMUNITY_CAD / STANDARD_RECONSTRUCTION | A-001 / A-005 | CAD placement / envelope; actual mating features: VERIFY ON HARDWARE
007 | Cytron MDD10A Rev2 | 1 | PURCHASED | MANUFACTURER_CAD | A-001 / A-005 | CAD placement / envelope; actual mating features: VERIFY ON HARDWARE
008 | Adafruit BNO085 | 1 | PURCHASED | MANUFACTURER_CAD | A-001 / A-005 | CAD placement / envelope; actual mating features: VERIFY ON HARDWARE
009 | ROCKET ES7-12 AGM battery | 1 | PURCHASED | DATASHEET / PHOTO_ESTIMATE | A-001 / A-005 | CAD placement / envelope; actual mating features: VERIFY ON HARDWARE
010 | SZH-JA020 covered fuse box | 1 | PURCHASED | DATASHEET / PHOTO_ESTIMATE / SELLER_DIMENSION | A-001 / A-005 | CAD placement / envelope; actual mating features: VERIFY ON HARDWARE
011 | FHAC main fuse holder | 1 | PURCHASED | MANUFACTURER_DRAWING / PHOTO_ESTIMATE / STANDARD_RECONSTRUCTION | A-001 / A-005 | CAD placement / envelope; actual mating features: VERIFY ON HARDWARE
012 | FHAC motor fuse holder | 1 | PURCHASED | MANUFACTURER_DRAWING / PHOTO_ESTIMATE / STANDARD_RECONSTRUCTION | A-001 / A-005 | CAD placement / envelope; actual mating features: VERIFY ON HARDWARE
013 | 12V relay / socket | 1 | PURCHASED | DATASHEET / PHOTO_ESTIMATE | A-001 / A-005 | CAD placement / envelope; actual mating features: VERIFY ON HARDWARE
014 | Positive busbar | 1 | PURCHASED | ASSUMED | A-001 / A-005 | CAD placement / envelope; actual mating features: VERIFY ON HARDWARE
015 | Negative busbar | 1 | PURCHASED | ASSUMED | A-001 / A-005 | CAD placement / envelope; actual mating features: VERIFY ON HARDWARE
016 | SZH-EK366 5V converter | 1 | PURCHASED | ASSUMED / PHOTO_ESTIMATE / SELLER_DIMENSION / STANDARD_RECONSTRUCTION | A-001 / A-005 | CAD placement / envelope; actual mating features: VERIFY ON HARDWARE
017 | 12V to19V boost converter | 1 | PURCHASED | PHOTO_ESTIMATE / SELLER_DIMENSION | A-001 / A-005 | CAD placement / envelope; actual mating features: VERIFY ON HARDWARE
018 | KGE-N&H E-STOP | 1 | PURCHASED | MANUFACTURER_CAD | A-001 / A-005 | CAD placement / envelope; actual mating features: VERIFY ON HARDWARE
019 | Main rocker switch | 1 | PURCHASED | PHOTO_ESTIMATE | A-001 / A-005 | CAD placement / envelope; actual mating features: VERIFY ON HARDWARE
020 | USB speaker SP001 envelope | 1 | PURCHASED | ASSUMED / PHOTO_ESTIMATE / STANDARD_RECONSTRUCTION | A-001 / A-005 | CAD placement / envelope; actual mating features: VERIFY ON HARDWARE
021 | Battery voltage divider | 1 | PURCHASED | ASSUMED | A-001 / A-005 | CAD placement / envelope; actual mating features: VERIFY ON HARDWARE
022 | NEXT505UHP USB hub | 1 | PURCHASED | DATASHEET / PHOTO_ESTIMATE | A-001 / A-005 | CAD placement / envelope; actual mating features: VERIFY ON HARDWARE
023 | MG90S pan servo | 1 | PURCHASED | COMMUNITY_CAD | A-001 / A-005 | CAD placement / envelope; actual mating features: VERIFY ON HARDWARE
024 | MG90S tilt servo | 1 | PURCHASED | COMMUNITY_CAD | A-001 / A-005 | CAD placement / envelope; actual mating features: VERIFY ON HARDWARE
025 | Pan horn | 1 | PURCHASED | PHOTO_ESTIMATE | A-001 / A-005 | CAD placement / envelope; actual mating features: VERIFY ON HARDWARE
026 | Tilt horn | 1 | PURCHASED | PHOTO_ESTIMATE | A-001 / A-005 | CAD placement / envelope; actual mating features: VERIFY ON HARDWARE
027 | LS-F FRONT V-J166 | 1 | PURCHASED | ASSUMED / DATASHEET / PHOTO_ESTIMATE | A-001 / A-005 | CAD placement / envelope; actual mating features: VERIFY ON HARDWARE
028 | LS-R REAR V-J166 | 1 | PURCHASED | ASSUMED / DATASHEET / PHOTO_ESTIMATE | A-001 / A-005 | CAD placement / envelope; actual mating features: VERIFY ON HARDWARE
029 | LS-L LEFT V-J166 | 1 | PURCHASED | ASSUMED / DATASHEET / PHOTO_ESTIMATE | A-001 / A-005 | CAD placement / envelope; actual mating features: VERIFY ON HARDWARE
030 | LS-Rt RIGHT V-J166 | 1 | PURCHASED | ASSUMED / DATASHEET / PHOTO_ESTIMATE | A-001 / A-005 | CAD placement / envelope; actual mating features: VERIFY ON HARDWARE
031 | WD SN530 2242 SSD | 1 | PURCHASED | DATASHEET / PHOTO_ESTIMATE | A-001 / A-005 | Existing provision. Verify hardware compatibility / procurement / electrical interface.
032 | ADC carrier / hardware VERIFY | 1 | FABRICATED | CUSTOM | F-221 | Existing provision. Verify hardware compatibility / procurement / electrical interface.
033 | Encoder level interface | 1 | PURCHASED | ASSUMED / DATASHEET | A-001 / A-005 | Existing provision. Verify hardware compatibility / procurement / electrical interface.
101 | CUSTOM_BOTTOM_PLATE | 1 | FABRICATED | CUSTOM | F-101 | PVC foam / Fomex; through profile
102 | CUSTOM_BATTERY_PLATE | 1 | FABRICATED | CUSTOM | F-102 | PVC foam / Fomex; through profile
103 | CUSTOM_CHASSIS_PAD_0_0 | 1 | FABRICATED | CUSTOM | F-103 | PVC foam / Fomex; 3D relief - STEP controls
104 | CUSTOM_CHASSIS_PAD_0_1 | 1 | FABRICATED | CUSTOM | F-104 | PVC foam / Fomex; through profile
105 | CUSTOM_CHASSIS_PAD_1_0 | 1 | FABRICATED | CUSTOM | F-105 | PVC foam / Fomex; 3D relief - STEP controls
106 | CUSTOM_CHASSIS_PAD_1_1 | 1 | FABRICATED | CUSTOM | F-106 | PVC foam / Fomex; through profile
107 | CUSTOM_CHASSIS_PAD_2_0 | 1 | FABRICATED | CUSTOM | F-107 | PVC foam / Fomex; 3D relief - STEP controls
108 | CUSTOM_CHASSIS_PAD_2_1 | 1 | FABRICATED | CUSTOM | F-108 | PVC foam / Fomex; through profile
109 | CUSTOM_CHASSIS_PAD_3_0 | 1 | FABRICATED | CUSTOM | F-109 | PVC foam / Fomex; 3D relief - STEP controls
110 | CUSTOM_CHASSIS_PAD_3_1 | 1 | FABRICATED | CUSTOM | F-110 | PVC foam / Fomex; through profile
111 | CUSTOM_ELECTRONICS_PLATE | 1 | FABRICATED | CUSTOM | F-111 | PVC foam / Fomex; through profile
112 | CUSTOM_LEFT_PANEL | 1 | FABRICATED | CUSTOM | F-112 | PVC foam / Fomex; through profile
113 | CUSTOM_RIGHT_PANEL | 1 | FABRICATED | CUSTOM | F-113 | PVC foam / Fomex; through profile
114 | CUSTOM_REAR_PANEL | 1 | FABRICATED | CUSTOM | F-114 | PVC foam / Fomex; 3D relief - STEP controls
115 | CUSTOM_FRONT_PANEL | 1 | FABRICATED | CUSTOM | F-115 | PVC foam / Fomex; through profile
116 | CUSTOM_LIDAR_BRIDGE | 1 | FABRICATED | CUSTOM | F-116 | PVC foam / Fomex; through profile
117 | CUSTOM_LIDAR_PLATE | 1 | FABRICATED | CUSTOM | F-117 | PVC foam / Fomex; through profile
118 | CUSTOM_JETSON_CRADLE | 1 | FABRICATED | CUSTOM | F-118 | PVC foam / Fomex; 3D relief - STEP controls
119 | CUSTOM_BATTERY_STOP_FRONT | 1 | FABRICATED | CUSTOM | F-119 | PVC foam / Fomex; through profile
120 | CUSTOM_BATTERY_STOP_REAR | 1 | FABRICATED | CUSTOM | F-120 | PVC foam / Fomex; through profile
121 | CUSTOM_BATTERY_STOP_LEFT | 1 | FABRICATED | CUSTOM | F-121 | PVC foam / Fomex; through profile
122 | CUSTOM_BATTERY_STOP_RIGHT | 1 | FABRICATED | CUSTOM | F-122 | PVC foam / Fomex; through profile
123 | CUSTOM_HUB_TRAY | 1 | FABRICATED | CUSTOM | F-123 | PVC foam / Fomex; 3D relief - STEP controls
124 | CUSTOM_POWER_BACKPLANE | 1 | FABRICATED | CUSTOM | F-124 | PVC foam / Fomex; 3D relief - STEP controls
125 | CUSTOM_FUSE_SHELF | 1 | FABRICATED | CUSTOM | F-125 | PVC foam / Fomex; 3D relief - STEP controls
126 | CUSTOM_BOOST_BASE | 1 | FABRICATED | CUSTOM | F-126 | PVC foam / Fomex; 3D relief - STEP controls
127 | CUSTOM_FUSEBLOCK_TRAY | 1 | FABRICATED | CUSTOM | F-127 | PVC foam / Fomex; 3D relief - STEP controls
128 | CUSTOM_JETSON_BASE_RETAINER_LEFT | 1 | FABRICATED | CUSTOM | F-128 | Stock material - VERIFY ON HARDWARE; 3D relief - STEP controls
129 | CUSTOM_JETSON_BASE_RETAINER_RIGHT | 1 | FABRICATED | CUSTOM | F-129 | Stock material - VERIFY ON HARDWARE; 3D relief - STEP controls
130 | CUSTOM_RELAY_TRAY | 1 | FABRICATED | CUSTOM | F-130 | PVC foam / Fomex; 3D relief - STEP controls
131 | CUSTOM_CAMERA_BASE | 1 | FABRICATED | CUSTOM | F-131 | PVC foam / Fomex; through profile
132 | CUSTOM_PAN_SERVO_MOUNT | 1 | FABRICATED | CUSTOM | F-132 | PVC foam / Fomex; through profile
133 | CUSTOM_PAN_YOKE | 1 | FABRICATED | CUSTOM | F-133 | PVC foam / Fomex; 3D relief - STEP controls
134 | CUSTOM_PAN_ARM_LEFT | 1 | FABRICATED | CUSTOM | F-134 | PVC foam / Fomex; through profile
135 | APPROX_CAM_L_LEFT | 1 | FABRICATED | MODIFIED_STOCK_BRACKET | F-135 | Modified stock metal L bracket; 3D relief - STEP controls
136 | CUSTOM_PAN_ARM_RIGHT | 1 | FABRICATED | CUSTOM | F-136 | PVC foam / Fomex; through profile
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

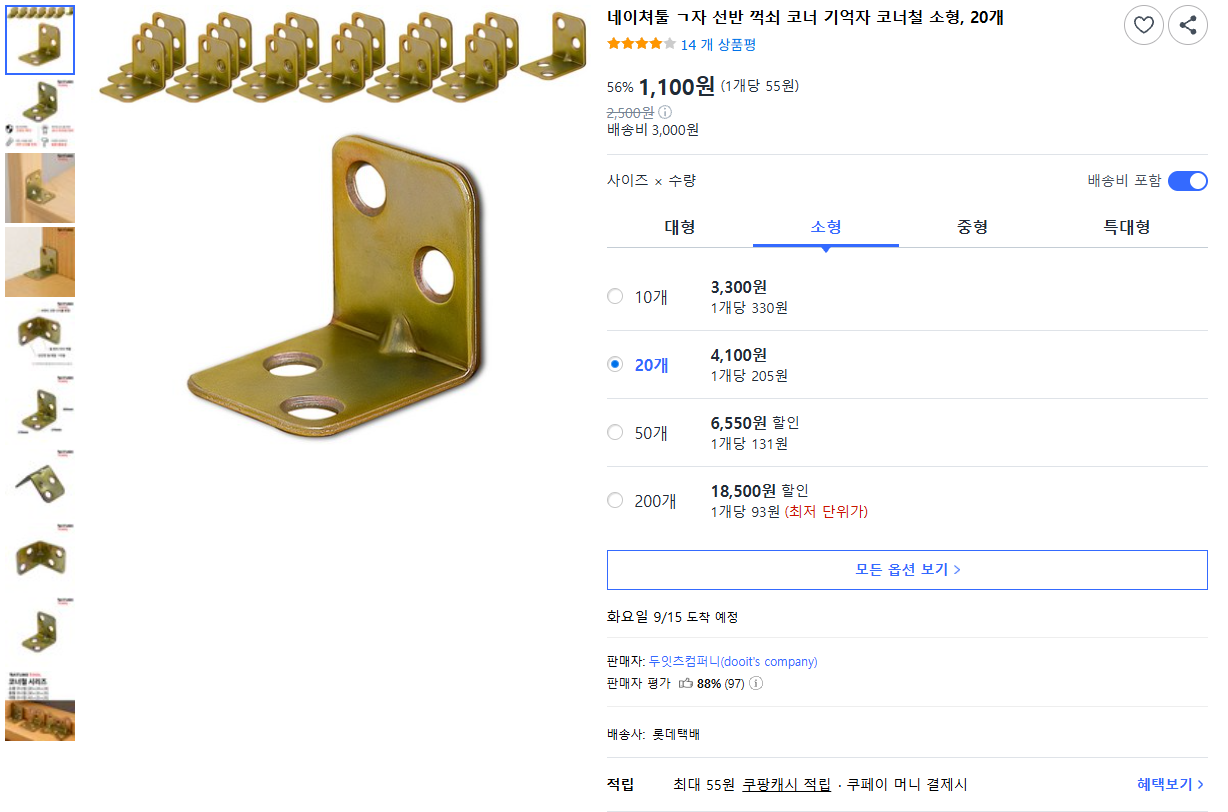
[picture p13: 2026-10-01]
assets/purchase-evidence/naturetool-small.png

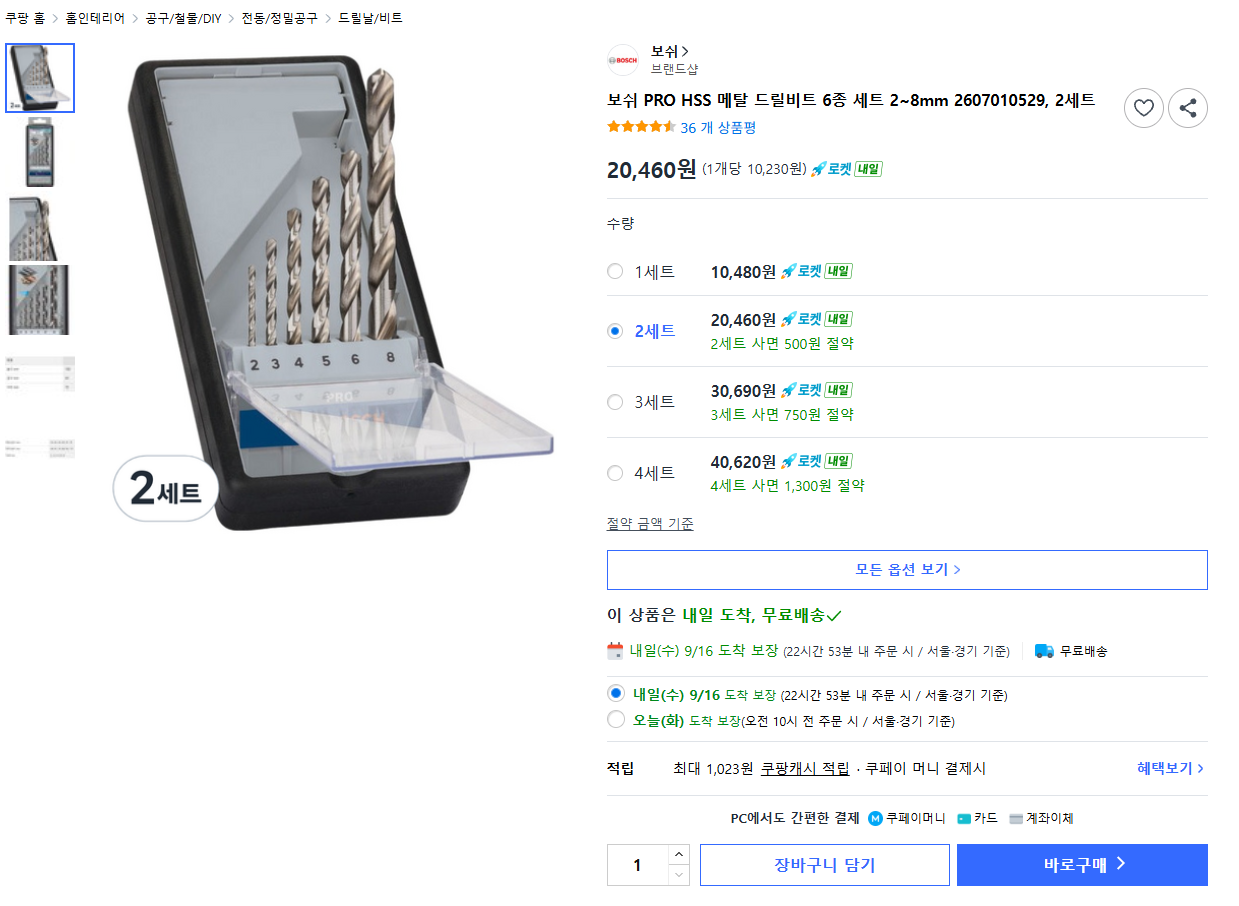
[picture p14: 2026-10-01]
assets/purchase-evidence/bosch-drills.png

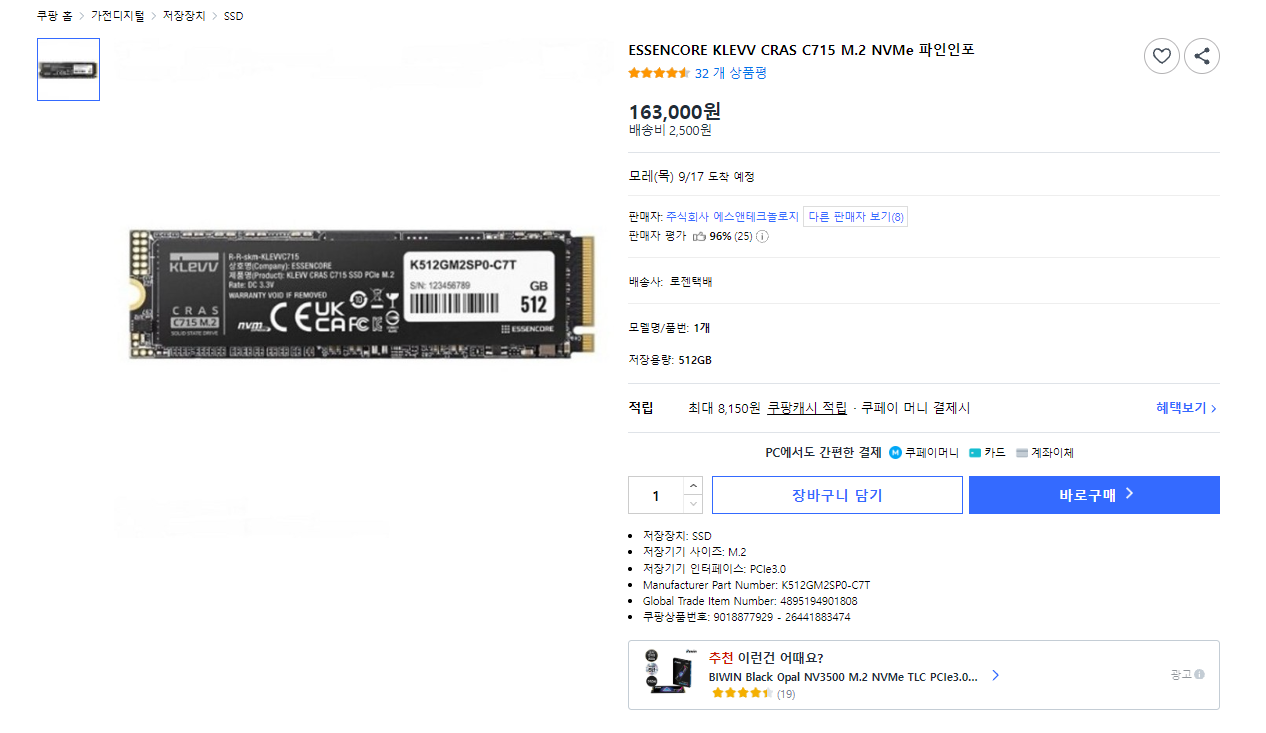
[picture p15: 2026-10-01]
assets/purchase-evidence/c715-512gb.png

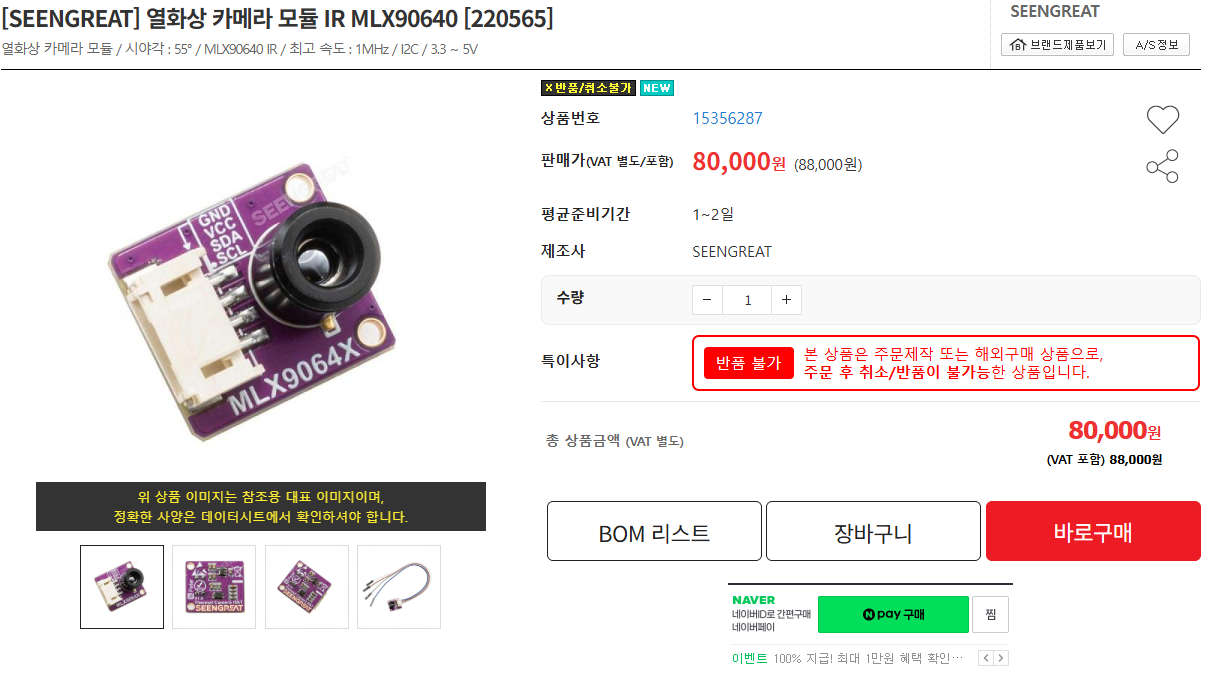
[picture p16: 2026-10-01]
assets/purchase-evidence/seengreat-220565.png

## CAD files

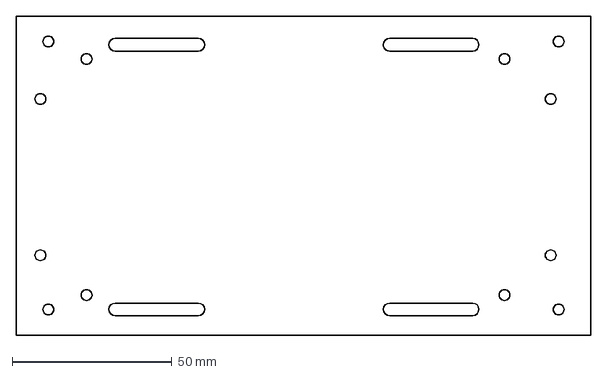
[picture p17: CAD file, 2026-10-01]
cad/procurement-review/dxf-review-only/CUSTOM_BATTERY_PLATE.dxf
180.0 x 100.0 mm

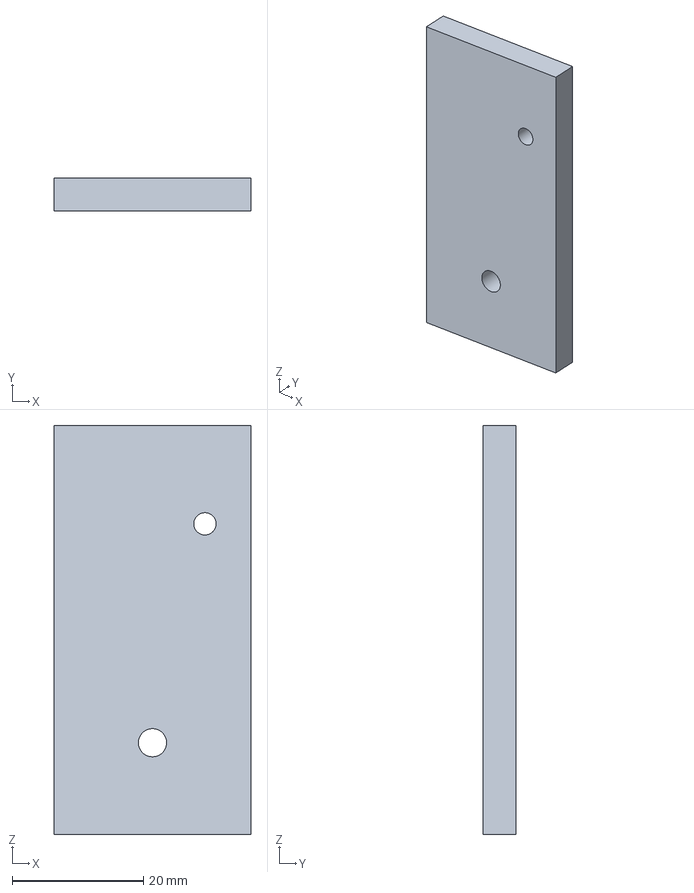
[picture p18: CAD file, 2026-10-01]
cad/procurement-review/part-step/CUSTOM_RIGHT_GUIDE_HANGER_0.step
30.0 x 5.00 x 62.4 mm

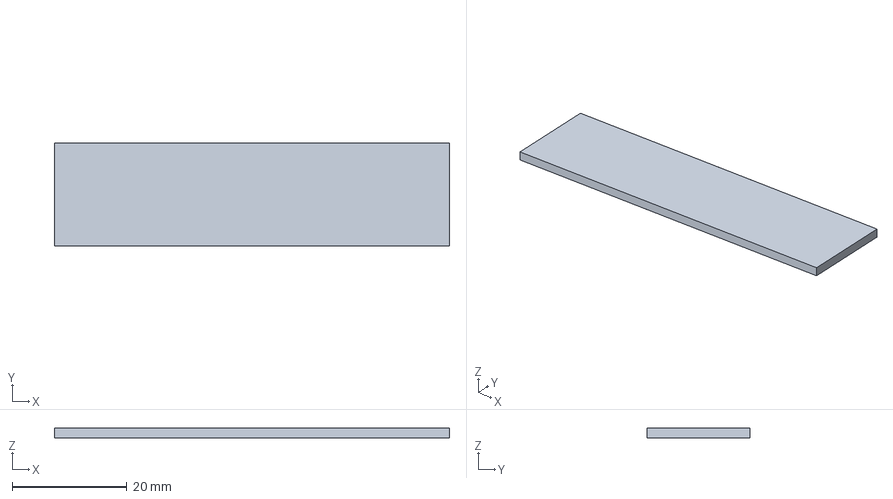
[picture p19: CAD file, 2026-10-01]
cad/procurement-review/purchased-step/PURCHASE_C715_COMPONENT_ENVELOPE.step
69.0 x 18.0 x 1.70 mm

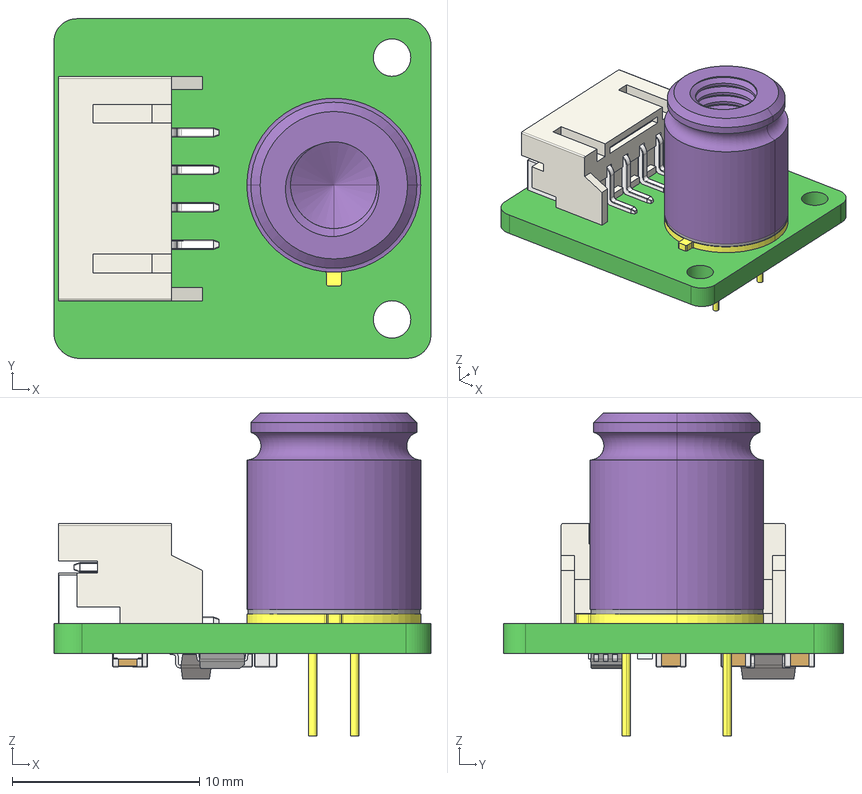
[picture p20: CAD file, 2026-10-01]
cad/procurement-review/source/SEENGREAT_220565_manufacturer.stp
20.2 x 18.2 x 17.3 mm
R_0603866 x 5
LOGO_ x 5
LOGO_9444 x 7
C_060312508 x 7
MLX90640ESF-BAB-000-SP_step
VSSOP_DCU_MO-187CA]
SOT23-5-2
1_1_2_A
PH2_0_SMD-W__1_200 x 4

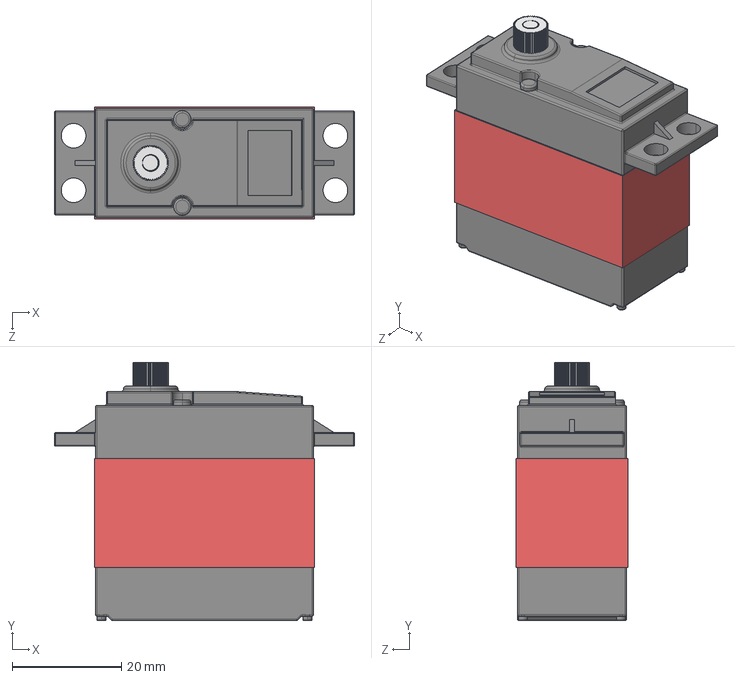
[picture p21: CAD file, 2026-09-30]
cad/ser0063-review/source/SER0063_USER_ORIGINAL.stp
55.0 x 47.4 x 20.5 mm

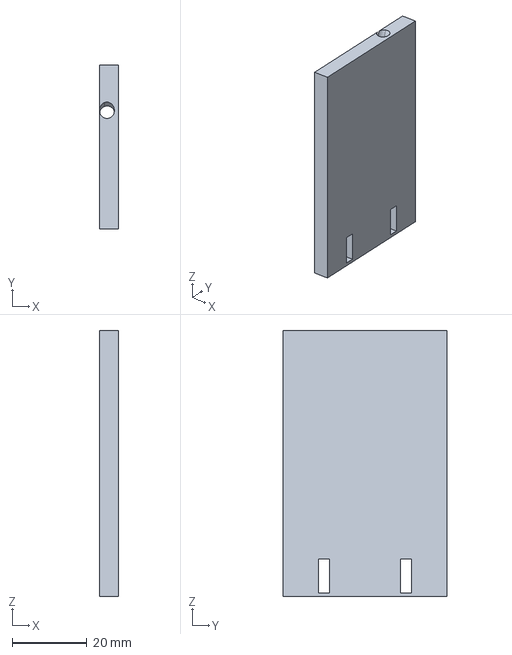
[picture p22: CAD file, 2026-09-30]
cad/v13-baseline/part-step/F-181_CUSTOM_REAR_SWITCH_BRACKET.step
5.00 x 44.0 x 71.4 mm

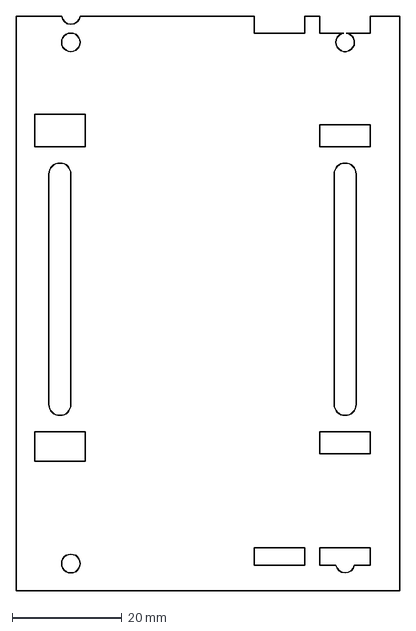
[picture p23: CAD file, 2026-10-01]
cad/procurement-review/dxf-review-only/CUSTOM_C920_SADDLE.dxf
70.0 x 104.8 mm

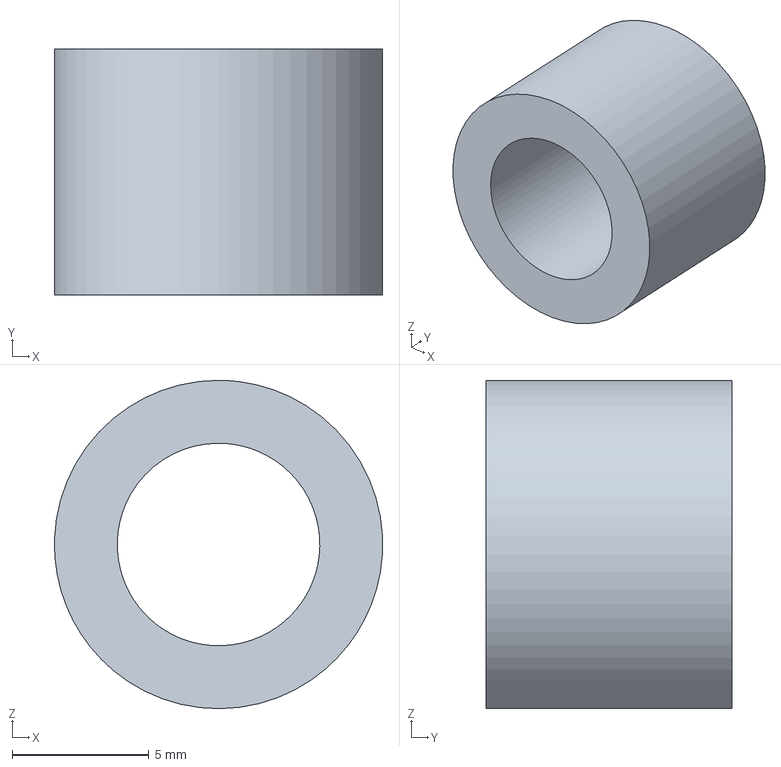
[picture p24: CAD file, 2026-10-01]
cad/procurement-review/part-step/CUSTOM_RIGHT_STOPPER_1.step
12.0 x 9.00 x 12.0 mm

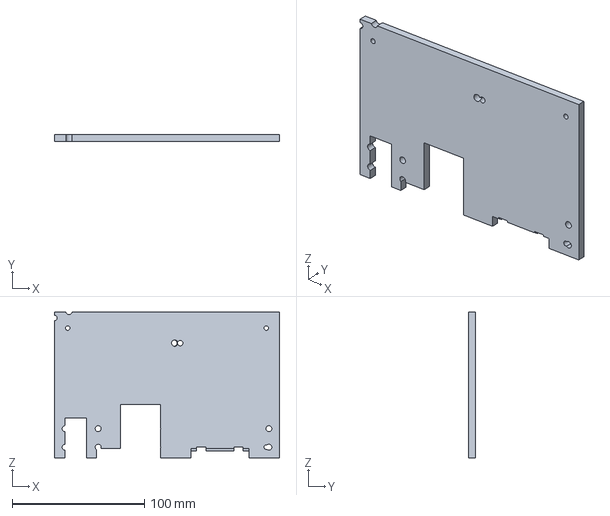
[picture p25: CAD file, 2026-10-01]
cad/procurement-review/purchased-step/CUSTOM_POWER_BACKPLANE.step
170.0 x 5.00 x 110.0 mm

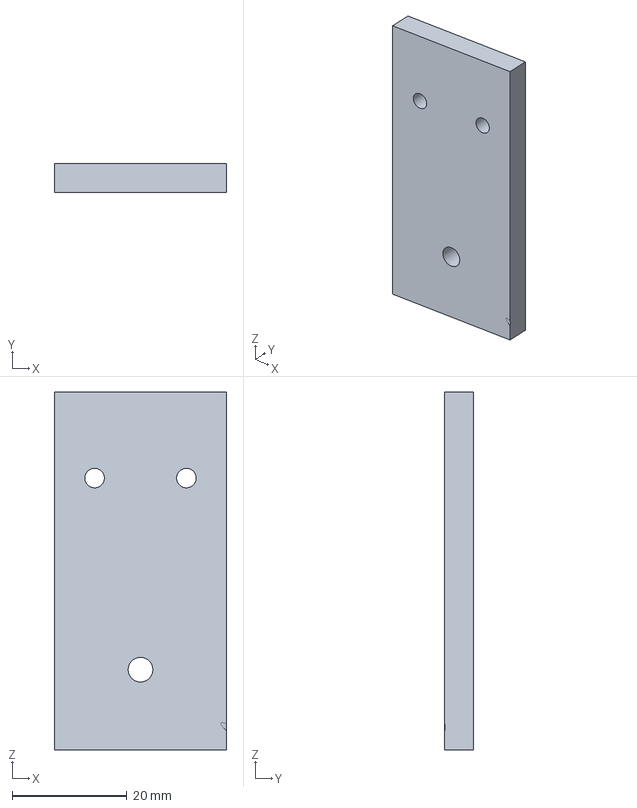
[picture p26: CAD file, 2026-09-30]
cad/v13-baseline/part-step/F-189_CUSTOM_LEFT_GUIDE_HANGER_0.step
30.0 x 5.00 x 62.4 mm

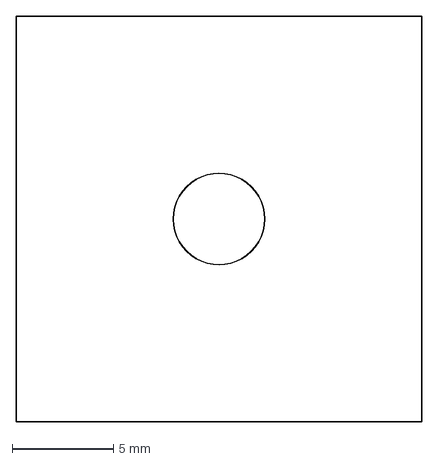
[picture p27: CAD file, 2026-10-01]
cad/procurement-review/dxf-review-only/CUSTOM_CHASSIS_PAD_1_1.dxf
20.0 x 20.0 mm

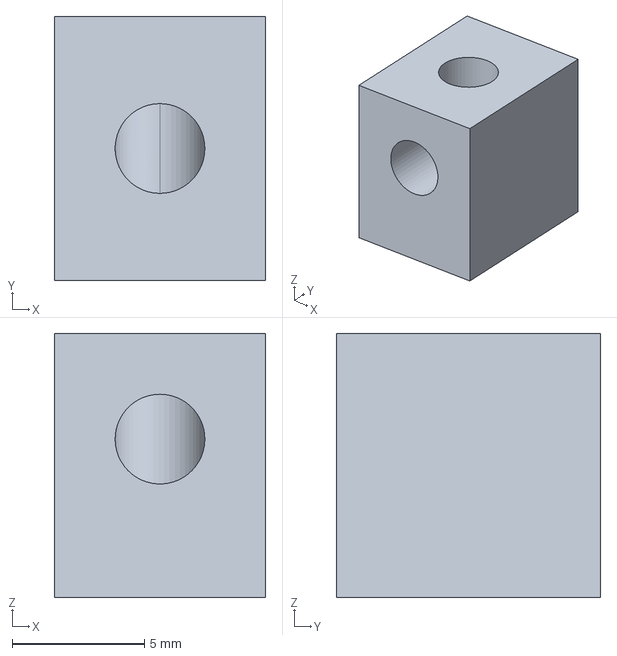
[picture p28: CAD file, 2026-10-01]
cad/procurement-review/part-step/CUSTOM_TILT_CORNER_LEFT1.step
8.00 x 10.0 x 10.0 mm

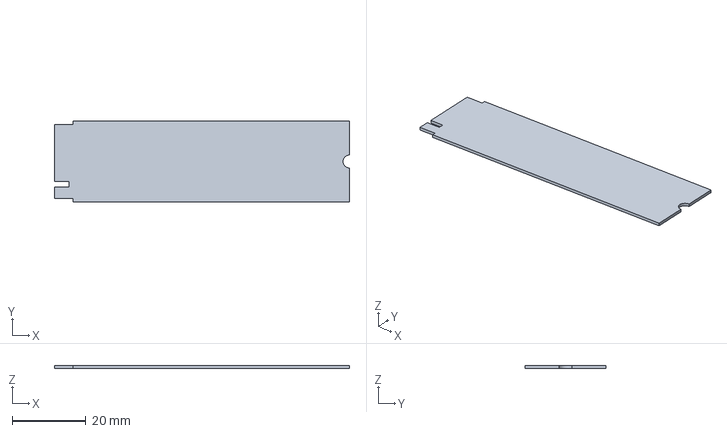
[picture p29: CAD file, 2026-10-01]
cad/procurement-review/purchased-step/PURCHASE_C715_512GB_PCB.step
80.0 x 22.0 x 0.8 mm

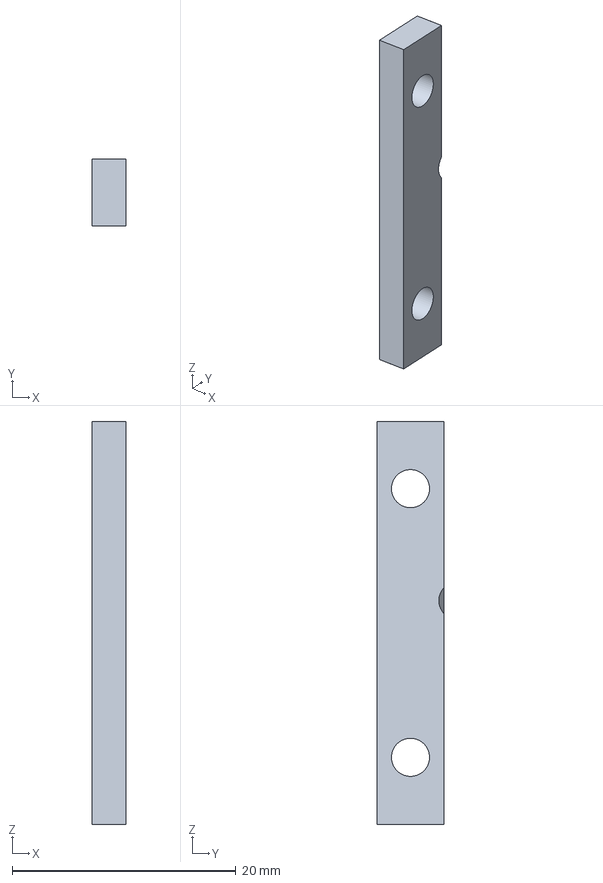
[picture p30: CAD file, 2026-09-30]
cad/v13-baseline/part-step/F-219_CUSTOM_SPEAKER_MOUNT_1.step
3.00 x 6.00 x 36.0 mm

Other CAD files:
cad/procurement-review/dxf-review-only/CUSTOM_TILT_CHEEK_LEFT.dxf
cad/procurement-review/part-step/CUSTOM_PAN_YOKE.step
cad/procurement-review/purchased-step/PURCHASE_SZH_CP003_OUTLINE.step
cad/v13-baseline/part-step/F-114_CUSTOM_REAR_PANEL.step
cad/procurement-review/dxf-review-only/CUSTOM_5V_DISTRIBUTOR.dxf
cad/procurement-review/dxf-review-only/CUSTOM_BATTERY_STOP_FRONT.dxf
cad/procurement-review/dxf-review-only/CUSTOM_BATTERY_STOP_LEFT.dxf
cad/procurement-review/dxf-review-only/CUSTOM_BATTERY_STOP_REAR.dxf
cad/procurement-review/dxf-review-only/CUSTOM_BATTERY_STOP_RIGHT.dxf
cad/procurement-review/dxf-review-only/CUSTOM_CAMERA_BASE.dxf
cad/procurement-review/dxf-review-only/CUSTOM_CHASSIS_PAD_0_1.dxf
cad/procurement-review/dxf-review-only/CUSTOM_CHASSIS_PAD_2_1.dxf
cad/procurement-review/dxf-review-only/CUSTOM_CHASSIS_PAD_3_1.dxf
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

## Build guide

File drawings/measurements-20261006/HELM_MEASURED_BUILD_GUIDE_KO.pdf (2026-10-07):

# HELM / 실측 반영 CAD와 제작 가이드

MEASURED_LAYOUT_20261006 · 재단·통전 승인 전 | 1

### 현재 산출물

구매 93개 항목과 치수표 13개 기록을 연결했습니다. 이 중 10개에 실측 또는 근사 실측치가 있습니다. 전체 수정 조립체는 3,888개 노드이며 외곽 치수를 바꾼 형상은 26개입니다.

### 변경한 형상

로커: 몸통 Ø20 / 테두리 Ø27 / 전체 깊이 34.2와 위치 수정. C920: 본체 95W×28H×20D, 거치부 45W×18H×44D, 접힌 전체 깊이 57. 중형 꺽쇠 30×25×25와 소형 참고 20×24×24. 미구매 ADC 잔여 몸체 27 개 제거.

### 실측과 맞아 유지한 형상

CP003 100×45×33, 배터리 케이스 151×65×94(공식 단자 포함 98), 승압기 75×75×31, 퓨즈박스 53×86×42. SER0063 원본 55×20.5×47.38은 반올림된 실측값에 맞춰 축소하지 않았습니다.

### 아직 확정되지 않은 형상

꺽쇠 두께·홀·보강 돌기, 혼 연결과 회전부 실제 체결품은 미확정입니다. 구형 꺽쇠 체결 형상 160개, 카메라 스트랩 2개, 이동한 스위치 배선 1개를 무효 처리했습니다. 형상 생략은 조립 완료나 간섭 해결을 뜻하지 않습니다.

### 파일 사용 순서

부품표의 전체번호 → 필수확인 → 현장조정 → 같은 리비전 CAD·도면 순서로 보시면 됩니다. 부스바와 MG995 프 레임은 선택 재고 외곽 STEP으로 분리했으며 본체에 강제로 장착하지 않았습니다.

보유 판재는 5T 포맥스 600×900 mm 2장입니다. 128개 제작 후보가 모두 이 두 장에서 나오는 것은 아닙니다.

# 실측 치수 기록과 적용

번호 / 구매 ID | 확인한 치수 mm | CAD 반영
1 / P2-R79 | 100 × 45 × 33; 입력 나사 ≈7.5; 출력 개구 ≈5.5–6 | 외곽 유지; A/B는 고정홀이 아닙니다.
2 / P1-009 | 151 × 65 × 94 (케이스); 공식 단자 포함 98 | 기존 케이스와 단자 형상 유지
3 / P2-R30 | ≈55 × ≈20 × ≈47–48; 원본 CAD 55 × 20.5 × 47.38 | 원본 모터 2개 유지; 반올림한 20으로 축소하지 않음
4 / P2-R21 | 길이 300; 피치 2.0; 6핀 | 실측으로 집계하지 않음; 케이블 길이 정 보 기록
5 / P2-R56 | 설치할 길이만 선택 | 세트의 모든 스페이서를 측정할 필요 없 음
6 / P2-R54 | 20 × 24 × 24; 소형 실물 보유 불확실 | 외곽만 참고 CAD에 반영; 두께·홀·돌기 미확정
7 / P2-R55 | 30 × 25 × 25 | 기존 30 × 40 × 40 외곽 수정; 두께 2는 가정
8 / P2-R22 | 75 × 75 × 31 | 기존 형상 유지
9 / P1-016 | 53 × 86 × 42 | 기존 받침+덮개 전체 외곽 유지
11 / P1-018 | ≈165 × 15 × 18, 2개 | 선택 재고 외곽 STEP; 본체에 강제 장착 하지 않음
12 / P1-029 | 몸통 Ø≈20; 테두리 Ø≈27; 전체 34.2 | 외곽·뒤쪽 여유 수정. 구멍은 테두리 27 로 뚫지 않음
13 / P2-R78 | ㄷ자 64 × 55 × 25; 다른 프레임 58 × 37 × 25 | 선택 재고 외곽 STEP; 정밀 홀·회전축 미 생성
14 / P1-003 | 본체 95 × 20 × 28; 클립 44 × 45 × 18; 접힌 측면 전체 57 | 본체/클립 따로 보정. 상대 힌지 자세는 추정

원본 번호 10은 없습니다. 웹캠 구매 행 22는 모델명으로 대조해 P1-003 / 1차 7행에 연결했습니다. 중형의 25m는 25mm 오기로 정 규화했습니다. CP003의 A/B는 단자 크기이며 고정홀이 아닙니다.

# 먼저 확인할 핵심 4가지

### G1 / SER0063 출력 혼

실제 사용할 혼의 홀 중심 간격·지름·두께·축에 끼운 체결면 높이
회전축과 연결판의 위치가 바뀌어 재단 후 현장 보정이 어렵습니다.
완료 기준: 치수 스케치 또는 혼 STEP, 팬/틸트에 사용할 혼을 지정. 모터 몸체는 다시 잴 필요 없음

### G2 / 비상정지 스위치 장착부

실물 장착 지름·5T 판을 잡는 길이·뒤쪽 돌출
구매 22mm 표기와 기존 CAD 참조품의 일치가 확인되지 않았습니다. 큰 홀은 복구하기 어렵습니다. 완료 기준: 5T 자투리 끼움+너트 체결 시험과 후면 여유 확인. 맞으면 세부 외형 재측정 불필요

### G3 / 섀시 기준 홀과 판 두께

실물 섀시 상부 기준 4홀에 1:1 종이를 대조; 실제 판 두께와 가조립 높이
기준이 어긋나면 상하판·전산볼트 전체가 맞지 않습니다.
완료 기준: 네 점 모두 맞으면 새로 전부 측정할 필요 없음. 다르면 해당 홀 중심 좌표만 측정

### G4 / 범퍼 스위치와 복귀 기구

작동점·여유 이동·복귀 확인; 실제 스프링/가이드 보유 여부
기존 4mm 스트로크·2mm 작동점은 가정이며 멈춤과 복귀 기능에 영향을 줍니다.
완료 기준: 간이 지그에서 네 방향을 눌러 작동과 복귀를 확인. 미보유 스프링 등을 가상 재고로 취급하지 않음

모터 본체·작은 칩을 다시 전부 재는 작업은 필요하지 않습니다. 실제 혼의 스케치, 시험 끼움, 기준 4홀 종이 대조, 범퍼 기능 시험으로 필요한 범위를 확인합니다.

# 현장에서 조정할 항목

### 고정 ㄱ자 꺽쇠·CP003·퓨즈박스

실물 놓기 → 덮개/공구 여유 확인 → 홀 중심 전사 → 가조립 기존 CAD의 가정 홀을 먼저 모두 뚫지 않습니다.

### PCB·허브·USB 스피커

보드 모서리와 커넥터 여유를 맞춘 뒤 스페이서/벨크로 위치 선택 작은 칩 개별 측정 불필요. PCB 자체 홀을 임의로 넓히지 않습니다.

### M3 스페이서·M4 전산볼트

실물 적층 높이와 너트·와셔에 맞춰 필요한 길이만 선택/최종 절단 회전부에서는 돌출 나사 끝과 공구 접근을 확인합니다.

### EVA·벨크로·케이블

실제 압축 두께와 여유 길이로 현장 조정
방열구·배터리 단자·가동부를 덮거나 케이블을 팽팽하게 당기지 않습니다.

### 미사용 재고·공구·개별 칩

전체 구매 목록에는 유지하되 로봇 CAD에 강제로 장착하지 않음 부스바와 MG995 프레임은 별도 선택 재고 형상입니다.

### 선택 부품과 회전부의 조건

MG995 프레임은 회전축·하중부로 채택할 때만 내측 폭·홀·두께를 확인합니다. 소형 꺽쇠의 실물 보유는 불확실합 니다. 중형으로 대체하려면 혼과 함께 회전부 배치를 다시 검사해야 합니다.

재고 미확인: 범퍼 스프링·가이드, LiDAR 40 mm 슬리브, 코너블록·부시, M2/M2.5 기계나사, 2T ESP 받침·소켓, 1.6T 5V 분배기판과 엔코더 레벨 회로. CAD에 있다는 이유만으로 보유 재료로 계산하지 않습니다.

# 판재 재단과 조립 순서

### 1 / 기준과 재료 확인

5T 실물 두께를 확인하고 섀시 기준 4홀에 1:1 종이를 대조합니다. 회전부 연결판과 큰 스위치 홀은 핵심 확인이 끝 나기 전 최종 재단하지 않습니다.

### 2 / 100% 출력과 시험 조각

A3 윤곽 도면은 실제 크기 100%, 페이지 맞춤 해제로 출력합니다. 100 mm 기준선을 자로 확인합니다. 로커는 아 래 Ø20 시험 홀로 5T 끼움·걸림턱을 확인하며 Ø27로 뚫지 않습니다.

### 3 / 외곽 재단과 홀 전사

판에 번호·기준 모서리를 표시하고 공구 여유·절삭 폭을 포함해 배치합니다. 판을 고정한 후 외곽을 가공하고 고정 꺽쇠·단자대 홀은 실물을 놓고 전사합니다. 기존 가정 홀을 먼저 전부 뚫지 않습니다.

### 4 / 가조립과 길이 확정

전원을 분리한 상태에서 하판·기둥·상판을 가조립합니다. 너트·와셔를 포함한 적층 높이로 전산볼트를 최종 절단합 니다. 카메라는 혼 확정과 간섭 수정 뒤 실제 체결품을 넣어 수동 회전 검사합니다.

### 5 / 마감과 기능 검사

절단면 마감 후 배터리 인출·덮개 열림·공구 접근·배선 여유를 확인합니다. 보유 비트는 2/3/4/5/6/8 mm입니다. Ø4.5 홀을 임의로 Ø5로 넓히지 말고 가공법부터 결정합니다.

로커 시험 조각 / 실제 크기 60×30 mm, 시작 홀 Ø20

5T 자투리에서 먼저 시험합니다.
장착 몸통은 약 Ø20입니다.
걸림턱과 후면 깊이도 확인합니다.

# 검증 범위와 남은 설계 작업

### CAD 검증

전체 STEP의 구문·부품명을 확인하고 수정한 26개 형상을 다시 읽어 치수를 대조했습니다. 제작 후보 STEP 128개 도 재읽기 검증했습니다. 전체 미변경 정지 부품의 모든 조합·강도·연속 회전·실물 동작을 검증한 결과는 아닙니다.

### 겹침과 회전부

변경부 후보 80쌍에서 0.5 mm³ 초과 겹침 24쌍을 기록했습니다. 이 중 C920 내부 참조 형상 4쌍은 별도로 표시했 습니다. 9개 팬·틸트 자세 검사에는 고유 10쌍이 남아 있습니다. 팬 ±45° / 틸트 ±20°는 검사 각도이며 승인 동작 범위가 아닙니다.

### 도면 사용 범위

DXF와 A3 윤곽 20개 중 19개는 5T, 1개는 1.6T 분배기판 참조입니다. 깊이가 다른 홈·다중 형상 판은 STEP으로 제공합니다. CUSTOM_LEFT_PANEL의 옛 꺽쇠 홀은 참고용이며 실물 전사 전 천공하지 않습니다. 측판의 새 로커 중심은 전체 좌표 X200 / Z239.389892 mm입니다.

### 외곽 모델의 한계

C920 힌지 상대 위치는 추정이며 실제 접힘 자세와 다를 수 있습니다. 로커 깊이의 내부 분할과 단자 블록도 여유 확인용입니다. MG995 프레임·부스바 별도 STEP은 외접 상자이며 상세 제조 CAD가 아닙니다.

### 앞선 문서와 충돌할 때

같은 리비전의 CAD·치수표·검증 기록을 우선합니다. 과거 FINAL/PASS 또는 디자인·추가 검색 불필요는 당시 확인 한 본체와 검사 범위에 한정됩니다. 실제 부품과 다른 연결부는 수정해야 합니다. LIB_SER0063.zip은 모터 몸체 CAD이며 혼 자료가 아닙니다.

핵심 4가지와 채택한 회전부 부품을 확인한 뒤 연결판·실제 체결품·간섭을 마무리하고 최종 재단·조립 도면을 다시 도출합니다. 현재 파 일은 실측 반영 전체 검토 조립체이며 제작 승인본은 아닙니다.

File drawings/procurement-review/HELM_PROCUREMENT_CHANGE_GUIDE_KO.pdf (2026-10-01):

HELM / 구매품 반영 CAD 검토

# 확인한 부품을 전체 모델에 적용

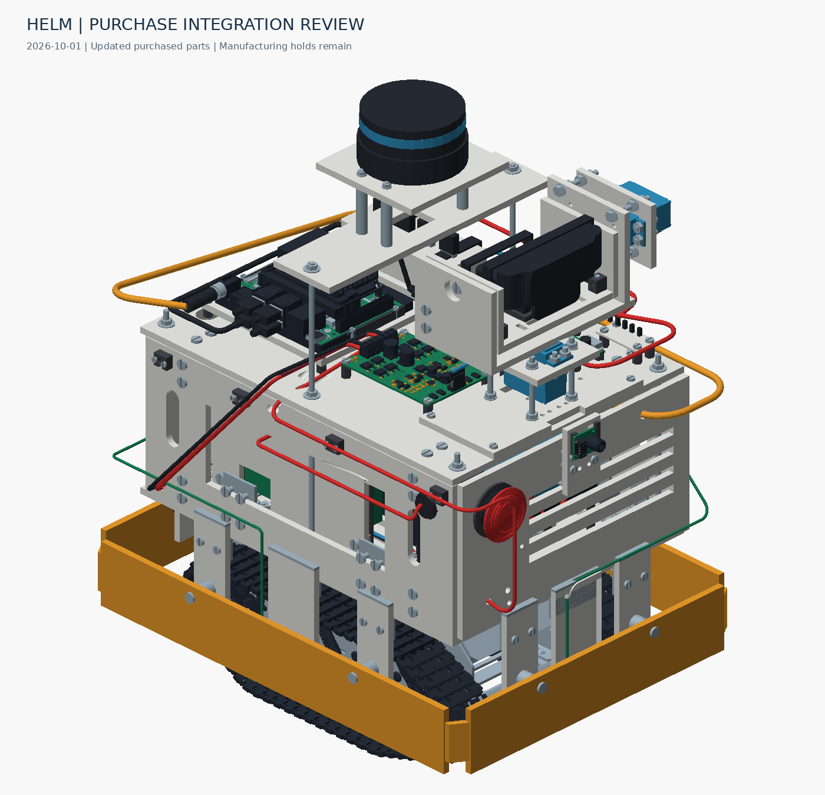
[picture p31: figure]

PROCUREMENT_REVIEW_20261001 | 재단·통전 승인 전 | 1 / 6

최신 조립체는 4,078개 노드입니다. SER0063 수정 위에 SSD·배전 외곽·전원 받침판을 반영하고, 구매하지 않은 ADC 받침과 잘못된 연결 형상을 제외했습니다.

### 이번 수정

C715 512GB를 실제 Jetson 2280 위치에 배치 / CP003 100×45×33 mm 공간 모델 / 전원판의 구형 홀 정리와 하단 간섭 홈 / 열화상 제조사 본체 유지 및 PH2.0 정정

현재 제작 대상 STEP 128개와 일정 두께가 확인된 DXF 20개를 다시 도출했습니다. 카메라 간섭 15쌍과 혼·브래킷 실 측이 남아 있어 최종 재단본으로 승인하지 않았습니다.

# SSD: 실제 2280 슬롯으로 교체

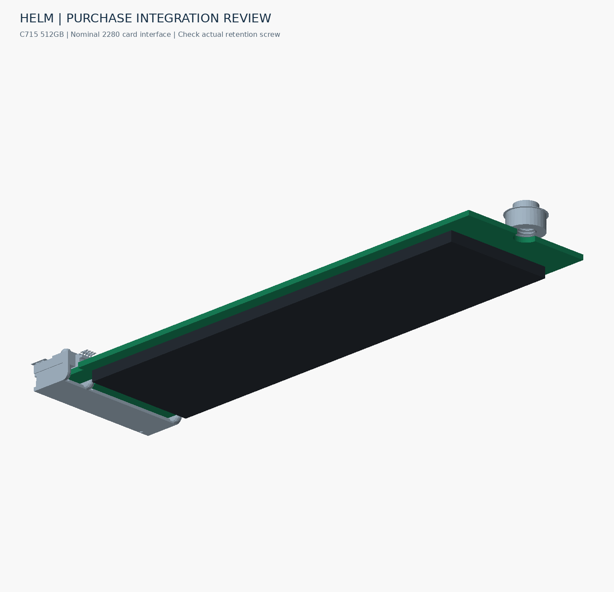
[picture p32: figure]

### C715 512GB, 2차 83행

제조사 명목 외형 80×22×2.5 mm입니다. 기존 WD 2242 참조와 선택형 2230 SSD를 제거하고 실제 2280 소켓·끝 단 지지부 기준으로 배치했습니다.

### 정확한 범위

PCB 카드 끝·키·칩은 결합 공간을 확인하는 명목 모델입니다. 복원 시 카드 진입부의 미세 여유를 다시 구성했습니다. 공급사의 정확한 기판·칩 제조 CAD는 아니며, 실제 끼움·고정나사·장착 여유는 확인이 필요합니다.

소켓 OFFICIAL_JETSON_0564_Solid / 끝단 지지 OFFICIAL_JETSON_0705_Solid. 끝단 기준 중심 XYZ = (102.795, 64.377, 273.324) mm. 단순히 이전 42 mm 카드를 80 mm로 늘린 위치가 아닙니다.

# 배전: 외곽과 전원판 수정

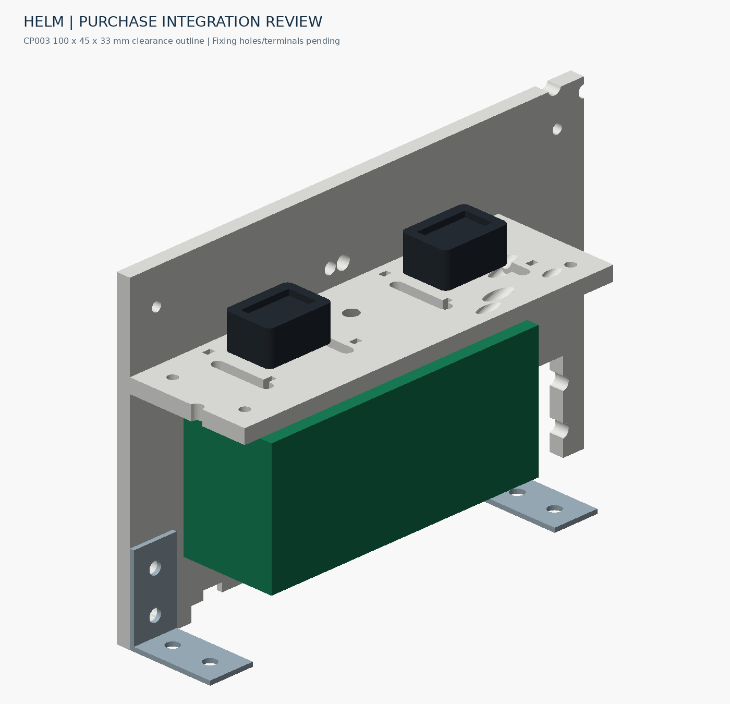
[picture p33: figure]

### CP003 외곽 적용, 상세 고정부 보류

2차 79행의 100(L)×45(W)×33(H) mm를 녹색 공간 모델에 반영했습니다. 덮개 포함 외곽이며 단자·고정홀의 상세 CAD는 아닙니다. 고정홀과 덮개 개방 공간·전선 입구·내부 연결을 확인해야 합니다.

### 전원 백플레이트

불필요한 닫힌 홀 3개를 메웠고 기존 개구부 안의 1개 위치는 유지했습니다. 하단 폭 7×높이 8 mm 홈 2개로 범퍼 발 체 결품과의 겹침을 해소했습니다. 홈 중심의 전체 좌표 X는 125.970 / 153.970 mm입니다.

이 판은 다른 깊이 형상이 있어 STEP으로 제공합니다. CP003 입력 2/출력 8에 예전 14개 논리 접속점을 임의 배정하지 않았으며 관련 15개 배선 경로를 무효 처리했습니다.

# 열화상: 제조사 본체 유지

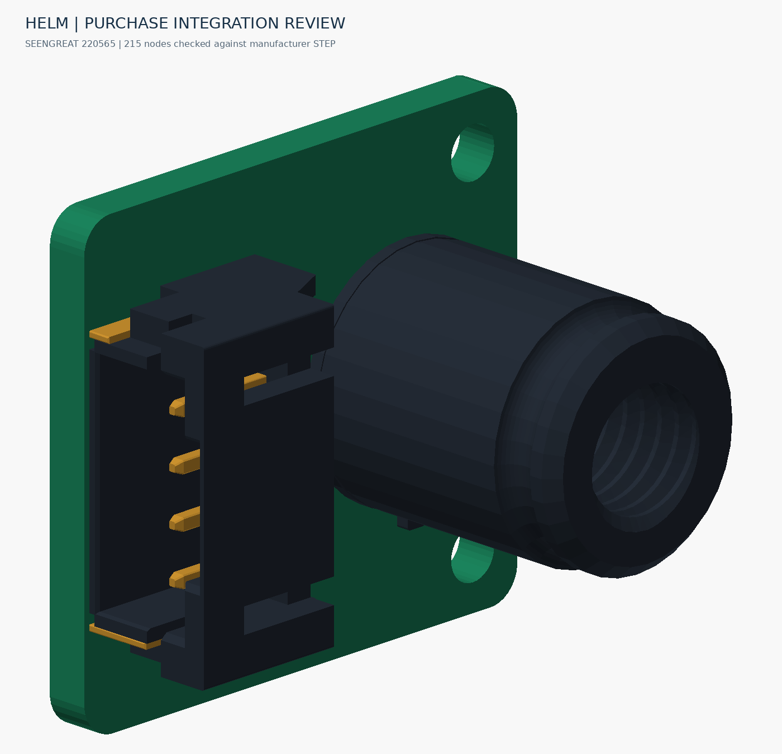
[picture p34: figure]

### SEENGREAT 220565 대조

제조사 HAT-V1.2 STEP을 확보해 기존 215개 형상의 경계·부피를 대조했습니다. 경계 오차 0.001 mm, 부피 차이 0.01 mm³ 미만 기준을 통과하여 기존 본체와 배치를 유지했습니다. 렌더링 색은 식별용입니다.

### PH2.0 4핀과 배선

포트 정보를 PH2.0 4핀으로 바로잡고 구형 2.54 mm 플러그 프록시를 제거했습니다. GND/VCC/SDA/SCL 기능은 확 인했지만, 결합 방향과 실제 리드선 출구·길이는 미확정입니다.

### 구매하지 않은 ADC 제외

ADS1115 받침·스페이서·체결품과 가짜 연결을 제거했습니다. 추가 구매를 전제하지 않으며 보유품으로 전압을 읽는 회로는 후속 확정 대상입니다. 배전·열화상·ADC를 합쳐 이번에 총 18개 경로를 무효 처리했습니다.

“본체 자료 불필요”는 확보한 본체 자료에만 해당합니다. 체결·강도·배선 또는 다른 부품의 설계 변경을 중단한다는 뜻이 아닙니다.

# 사용자께서 찾아 주실 자료

### 1. SER0063 동봉 혼

사용할 혼의 형상, 홀 중심 간격·지름, 두께, 축에 끼웠을 때의 상면 높이. 모터 몸체 CAD는 이미 확보했습니다.

### 2. MG995/MG996 브래킷

프레임별 안쪽 폭·높이·두께, 홀 좌표·지름, 원형 축 지지부 내경·외경·두께. 판매자 자 대조 사진만으로 정밀 가공을 확정하지 않습니다.

### 3. 네이쳐툴 소형·중형 꺽쇠

두 다리 길이·폭·두께, 홀 중심·지름, 굽힘부 보강 돌기 높이. 제품 사진은 확보했습니다.

### 4. SZH-CP003 고정부·단자

고정홀 중심 간격·지름, 덮개 개방 방향과 여유, 전선 입구 위치, 단자 내부 연결 그림. 외형 크기는 이미 적용했습니다.

### 추가 보유 규격

휴대형 스피커와 리미트 스위치의 정확한 치수, 전압센서, 너트·와셔·스페이서, 소형 기계나사, 범퍼 스프링·LiDAR 슬 리브와 1.6 mm 분배기판 재료·회로의 보유 여부를 확인해야 합니다.

정확한 치수도 또는 STEP이 있으면 실측 대신 보내 주세요. 이미 확보한 정면 사진을 다시 모을 필요는 없습니다. 자세한 범위는 docs/15-needed-measurements.md에 정리했습니다.

# 도면에서 제작으로 넘어가는 순서

### 01 / 최신 파일 확인

전체 모델은 CAD/HELM_PROCUREMENT_FULL_REVIEW.step입니다. EDITABLE/HELM_WORK에는 같은 BREP 4,078개와 메타데이터가 있습니다. 과거 FINAL/PASS는 당시 검사 범위에만 해당합니다.

### 02 / 치수·간섭·강도 확정

혼과 실제 브래킷·체결품을 적용하고 남은 카메라 간섭 15쌍을 해결합니다. 포맥스 강도·공구 접근·배터리 인출·움직 이는 케이블을 확인합니다.

### 03 / 재료와 판재 배치

보유 판재는 5T 포맥스 600×900 mm 2장입니다. 128개 형상이 모두 이 두 장에서 나오지는 않습니다. 1.6 mm 분배 기판은 포맥스 가공 대상이 아닙니다. 재료·수량 대조 뒤 공구 여유와 절삭 폭을 넣어 배치합니다.

### 04 / 출력 대조와 시험 조각

별도 A3 윤곽 20쪽은 1:1 검토용입니다. 실제 크기 100%로 인쇄하고 100 mm 선을 먼저 재세요. Bosch 비트는 2/3/4/5/6/8 mm이므로 D4.5 홀의 가공법을 먼저 확정해야 합니다. 임의로 5 mm로 넓히지 않습니다.

### 05 / 가공·가조립·단계 시험

번호·기준 모서리 표시 → 시험 조각 → 고정 후 절단·천공 → 마감 → 전원 분리 상태 가조립 → 전압·극성·보호 동작 확인 순서로 기록합니다. 최종 재단·결선도는 미확정 항목 해소 후 다시 도출합니다.

검사 범위: 이번 변경부 후보 29쌍에서 의도하지 않은 0.5 mm³ 초과 겹침 0건. 제작 STEP 128개 재읽기. 전체 STEP은 이름·구문과 변경 4개 형 상 확인. 전체 연속 회전·강도·실물 동작 승인은 포함하지 않습니다.

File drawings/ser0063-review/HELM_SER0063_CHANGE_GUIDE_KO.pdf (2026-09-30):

HELM / SER0063 / REVIEW 2026-09-30

# 모터 교체 CAD를 확인하세요

실제 첨부 STEP을 적용한 중간 검토본입니다. 기존 V13 전체 제작도는 이번 변경과 함께 다시 검토해야 합니다.

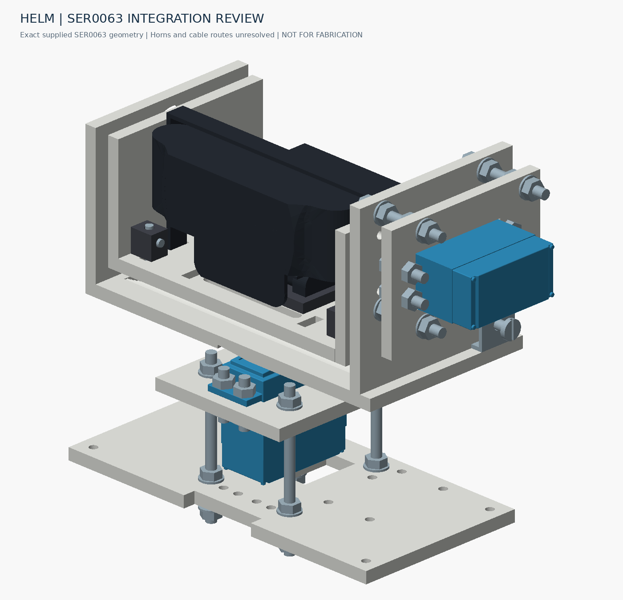
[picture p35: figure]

조립 검토용 - 재단·통전 승인용 최종본 아님 | 1 / 6

적용 기준: 1차는 이전 CSV의 왼쪽 구매 목록, 2차는 이번 XLSX입니다. 새 부품을 전부 넣지 않고, 기존 CAD와 실물 구성이 다른 항목을 교체 대상으로 정했 습니다.

## 이번에 반영한 변경

구분 | 반영 내용
모터 | MG90S 2개를 첨부 SER0063 STEP 2개로 교체. 모터 형상은 축척 변경 없이 배치했습니다.
장착 구조 | 팬·틸트 장착판, 지지봉 위치·길이, 오른쪽 지지판을 수정했습니다. 카메라 이동부를 위로 24.38 mm 이동했습니다.
미확정 연결 | 기존 MG90S 혼과 틸트 연결구를 제거했습니다. 새 혼 치수가 없어 구동축 연결은 아직 완성되지 않았습니다.
배선 | 기존 서보 2개 및 C920의 움직이는 케이블 경로를 제거하고 재배선 대기로 표시했습니다.

# 구매 목록을 CAD에 반영하는 기준

품목이 추가됐다는 이유만으로 장착하지 않습니다. 실물 교체·호환성·장착 목적을 나눠 판단합니다.

구매품 / 출처 | 이번 처리 | 남은 확인
SER0063 ×2 / 2주차 30행 | CAD 교체 완료 | 혼 실측, 하중과 배선
5T 포맥스 600 × 900 ×2 / 51행 | 장착판 재료 기준 | 합판으로 임의 대체하지 않음
M4 전산볼트 1 m ×5 / 52행 | 카메라 지지봉 검토안 | 실물 절단·끝단 정리·체결 여유
M3/M4/M5 혼합 세트 / 53행 | M4 너트·와셔 후보 | 규격별 실제 개수, 1세트/2세트 표기 차이
M4 풀림방지 너트 / 75행 | 구매품으로 기록 | CAD의 일반 너트와 높이가 다를 수 있음
MG995/MG996 브래킷 ×2 / 78행 | 호환 확인 전 미적용 | 실물 구멍 간격, 내측 폭, 두께
SZH-CP003 분배 단자대 / 79행 | 후속 교체 검토 대상 | 기존 배전부 대체 위치·단자 방향
KLEVV CRAS C715 / 83행 | 기존 SSD와 다른 품목으로 기록 | 보유 SSD 선택, 실제 규격·고정 위치
LED 패널·Edifier 스피커 / 81-82행 | 차체 장착을 강제하지 않음 | 전시용 사용 가능. 스피커 정확한 모델 필요
충전기 EO-1212 / 20행 | 새 구매 모델 기준으로 기록 | 기존 EO-1220 표기와 구분
공구·소모품 / 여러 행 | 가공·조립용으로 분류 | 차체 안에 모델을 억지로 넣지 않음

## 자료 해석 주의

### 이전 CSV는 1차 품목 29행을 사용했습니다. 이번 XLSX는 2주차 A20:I83의 64개 구매 행을 사용했습니다. 비교견적 시트의 예시·대체 견

적을 추가 구매품으로 세지 않았습니다.

### 기존 CAD의 ADS1115, 특수 길이 스페이서, 일부 체결품·범퍼 스프링은 실제 보유품과의 대조가 더 필요합니다. 전체 CAD가 구매품만으

로 완성됐다는 뜻은 아닙니다.

# 모터 기준 치수와 연결부

단위 mm. 치수 기준은 첨부 SER0063/3D/SER0063.stp이며, 제조사 규격은 보조 확인 자료입니다.

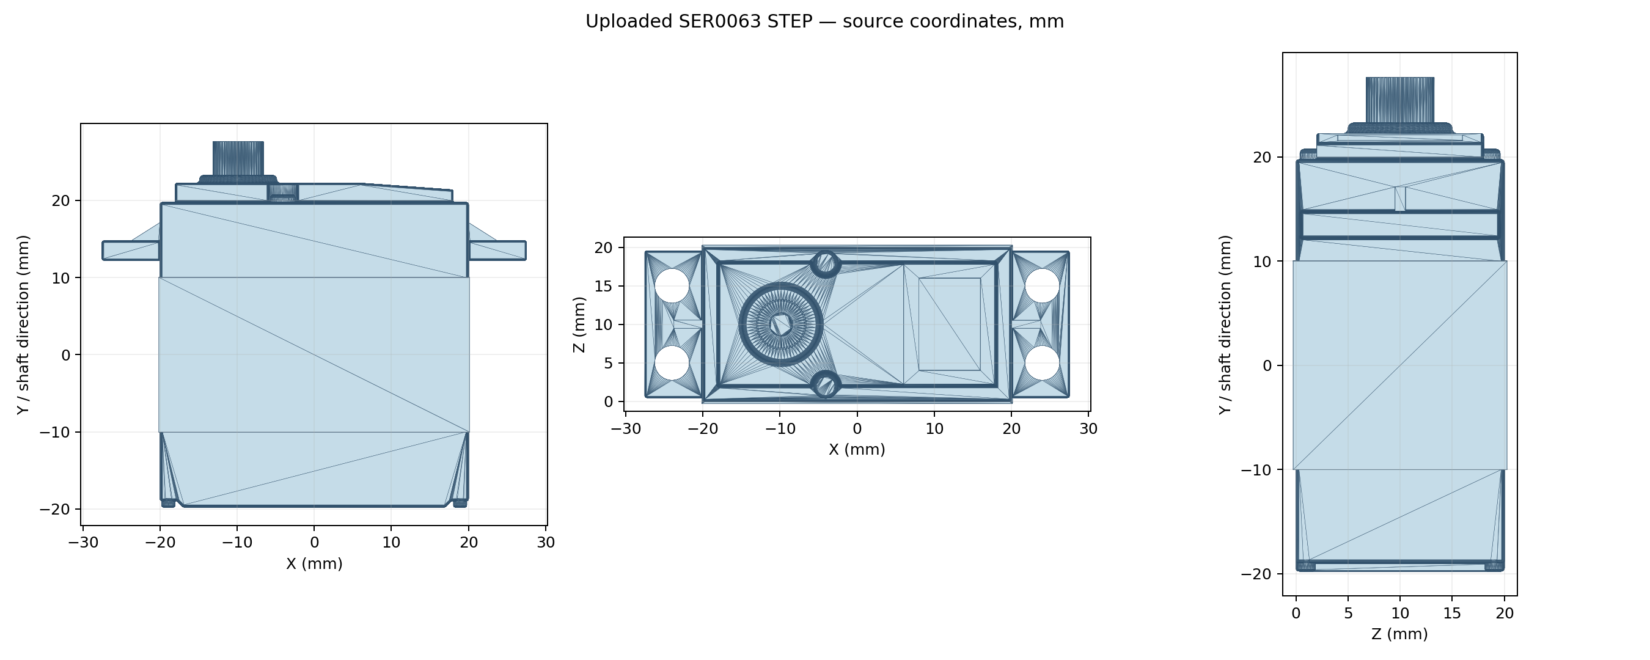
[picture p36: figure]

항목 | 확인값 / 의미
장착 홀 | 4개, 지름 4.5, 중심 간격 48 × 10
첨부 CAD 최대 외곽 | 55.00 × 47.38 × 20.50 (원본 X × Y × Z)
원본 출력축 | 축 방향 +Y, 축 끝 중심 (-9.86, 27.63, 10.00)
모델 구성 | 유효한 솔리드 1개. 혼·서보 리드선 형상은 포함되지 않음
제조사 표기 | 출력축 25T / 5.9 mm, 축 고정 나사 M3 × 6, 전원 5-8.4 V

## 혼 연결을 확정하려면

### 동봉 금속 혼의 ① 위에서 본 구멍 위치 ② 옆에서 본 두께와 축에 끼운 높이 ③ 중앙 고정 나사를 확인해야 합니다. 자를 댄 앞·옆 사진과 브

래킷의 앞·옆 사진을 준비해 주세요. 구멍 중심 간 거리는 실측값이 있으면 더 정확합니다.

### 현재 팬 축 위의 2 mm 공간은 혼을 넣기 위한 임시 배치값입니다. 실제 혼 두께로 확정한 수치가 아닙니다. 기존 MG90S 혼을 재사용한다

고 가정하지 않았습니다.

제조사: https://www.dfrobot.com/product-2787.html
첨부 STEP과 제품 치수도에서 장착 홀 간격을 대조했습니다. 확인일: 2026-09-30.

# 팬 모터 장착판 검토도

종이 대조용 1:1 형상입니다. 인쇄 시 실제 크기 100%를 선택하고, 아래 100 mm 기준선을 먼저 재어 보세요.

재단 보류: 이 평판은 모터 위치 검토용입니다. 혼 연결, 남은 간섭과 5T 포맥스 체결부 강도를 해결한 뒤 제작 치수를 확정해야 합니다.

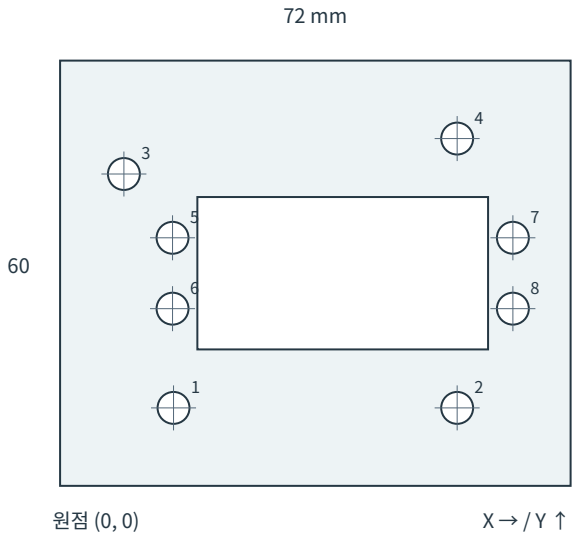
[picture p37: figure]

외곽 72 × 60
두께 5
장착 홀 8개: D4.5
중앙 창 41 × 21.5

1-4: 지지봉 홀
5-8: 모터 플랜지 홀

이 선을 자로 재면 100 mm여야 합니다.

홀 | X | Y | 홀 | X | Y
1 | 16.00 | 11.00 | 5 | 15.86 | 35.00
2 | 56.00 | 11.00 | 6 | 15.86 | 25.00
3 | 9.00 | 44.00 | 7 | 63.86 | 35.00
4 | 56.00 | 49.00 | 8 | 63.86 | 25.00

### 중앙 창의 왼쪽 아래: X 19.36, Y 19.25. 모서리 반경은 실제 가공 공구에 맞춰 다시 확인해야 합니다. CAD/DXF는 공구 경로와 절삭 폭 보

정이 없는 윤곽입니다.

### 지지봉은 64 mm ×4 검토안입니다. 왼쪽 뒤 지지점을 기존 위치에서 옮겨 ADC 받침과의 간섭을 피했습니다. 본체 플랜지와 중앙 창 사이

의 좁은 포맥스 구간은 하중 시험 없이 제작 확정하지 마세요.

대응 STEP과 DXF는 파일명 CUSTOM_PAN_SERVO_MOUNT로 찾으시면 됩니다. STEP은 조립 좌표이고, DXF는 평판의 왼쪽 아래가 원점인 mm 도면입니다.

# 틸트 모터 장착판 검토도

종이 대조용 1:1 형상입니다. 인쇄 시 실제 크기 100%를 선택하고, 아래 100 mm 기준선을 먼저 재어 보세요.

재단 보류: 이 평판은 모터 위치 검토용입니다. 혼 연결, 남은 간섭과 5T 포맥스 체결부 강도를 해결한 뒤 제작 치수를 확정해야 합니다.

외곽 72 × 49
두께 5
장착 홀 8개: D4.5
중앙 창 41 × 21.5

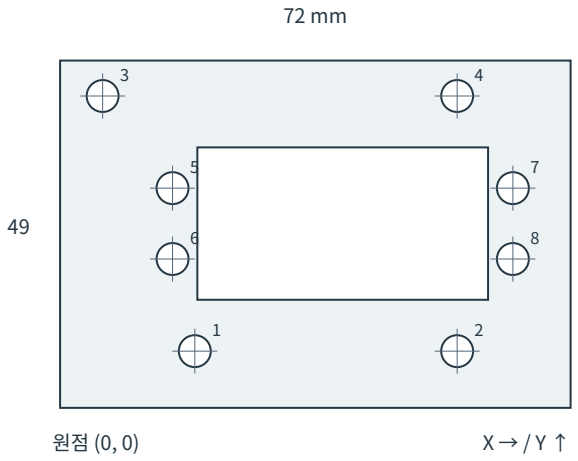
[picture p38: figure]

1-4: 지지봉 홀
5-8: 모터 플랜지 홀

이 선을 자로 재면 100 mm여야 합니다.

홀 | X | Y | 홀 | X | Y
1 | 19.00 | 8.00 | 5 | 15.86 | 31.00
2 | 56.00 | 8.00 | 6 | 15.86 | 21.00
3 | 6.00 | 44.00 | 7 | 63.86 | 31.00
4 | 56.00 | 44.00 | 8 | 63.86 | 21.00

### 중앙 창의 왼쪽 아래: X 19.36, Y 15.25. 모서리 반경은 실제 가공 공구에 맞춰 다시 확인해야 합니다. CAD/DXF는 공구 경로와 절삭 폭 보

정이 없는 윤곽입니다.

### 지지봉은 38 mm ×4 검토안입니다. 아래쪽 왼쪽 지지점을 옮겼습니다. 오른쪽 팬 지지판 높이는 11 mm 늘렸고, 장착판 상단은 라이다 받

침에 닿지 않도록 줄였습니다. 형상은 해당 PART_STEP 파일에서 확인하세요.

대응 STEP과 DXF는 파일명 CUSTOM_TILT_SERVO_MOUNT로 찾으시면 됩니다. STEP은 조립 좌표이고, DXF는 평판의 왼쪽 아래가 원점인 mm 도면입니다.

# 재단과 조립으로 이어가는 순서

지금 할 수 있는 종이 대조와, 실물 확인 뒤 진행할 재단·조립을 순서대로 정리했습니다.

## 1. 파일 열기

전체 배치는 CAD/HELM_SER0063_FULL_REVIEW.step, 카메라 집중 검토는 CAMERA_REVIEW.step을 여세요. 단위는 mm입니다. 파란 두 몸체가 첨부 SER0063입니다.

## 2. 종이로 먼저 맞추기

4-5쪽을 100%로 인쇄해 모터 플랜지와 대조합니다. 혼·브래킷 실측, 간섭 수정, 체결품 규격 확인 전에는 포맥스를 자르지 마세요.

## 3. 확정 뒤 판재 배치

### 600 × 900 판에 확정된 부품만 배치하고 번호·앞면·기준 모서리를 표시합니다. 현재 파일은 전체 판재 네스팅·수량 최적화 도면이 아닙

니다.

## 4. 확정 뒤 절단·천공

시험 조각에서 절삭 폭과 구멍을 먼저 확인합니다. 판을 받침판에 고정하고, 보유 칼·톱으로 여러 번 나눠 가공한 뒤 줄·사포로 맞춥니다. 드릴 구경은 도면과 실제 비트를 대조하세요.

## 5. 전산볼트와 가조립

### 검토 길이: 64 ×4, 38 ×4, 20 ×8 = 합계 568 mm (절단 손실 제외). 너트를 먼저 끼우고 고정해 절단한 뒤 끝단을 정리합니다. 실물 너트

높이에 맞춰 길이를 확정하세요.

## 6. 혼·배선·동작 확인

### 혼과 중앙 나사를 먼저 맞춰 손으로 천천히 움직여 간섭을 확인합니다. 3개 케이블 경로와 전원 용량을 다시 설계한 뒤 통전해야 합니다. 기

존 4.8 V 서보 배선 메모를 그대로 사용하지 마세요.

## 검증 결과와 제작 보류 이유

### 새 모터·지지 체결부는 검사한 136개 후보 쌍에서 0.5 mm³ 초과 겹침이 0건입니다. 부품 STEP 17개와 카메라 STEP 재불러오기에서 유

효한 형상을 확인했습니다.

### 팬 -45/0/+45°, 틸트 -20/0/+20°의 9개 조합을 검사했습니다. 기존 카메라 체결부 등에서 자세별 6-10건의 겹침이 남았습니다. 연속 회전

·하중·케이블 검증을 통과했다는 뜻이 아닙니다. 위치 설명은 ZIP의 OPEN_ISSUES_KO.md에 있습니다.

### 남은 핵심: 혼의 형상·장착 높이, 금속 브래킷 호환성, 기존 카메라 체결부 간섭, 포맥스 강도, 실물 체결품 규격, 전원과 배선. 이 사항을 반

영한 뒤 최종 재단도를 확정해야 합니다.

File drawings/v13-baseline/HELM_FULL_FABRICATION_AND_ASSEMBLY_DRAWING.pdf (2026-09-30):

Cover / source / drawing index | A-000
V13-REISSUE-20260929 | 2026-09-29 | mm | A3 | fitted views: use written dimensions | SHEET 1 / 202

# HELM Autonomous Inspection Robot

# Fabrication / Assembly / Wiring Drawing Set

# Source: HELM_V13_LATEST.step

Revision V13-REISSUE-20260929 | Date 2026-09-29 | Units mm | 202 sheets
STEP SHA256: 6942914ab1ea14b2dece5bdde453c85a6a909255873ff5ab9afa32673fce11da
SERIES | CONTENTS | USE
A | General views, locations, exploded groups, frame | Assembly / orientation
F-101 onward | 130 individual fabricated / modified components | Cut / drill / relief details
D | Fastening, camera, LiDAR, bumpers, battery | Assembly / adjustment
E | Power, signal, physical routing, connector access | Wiring / service reference
B | BOM and fastener quantities | Model-derived parts list
Q | Assembly order and pre-fabrication checklist | Build / verification

VERIFIED CAD: values measured from final model. ASSEMBLY ADJUST: position / relief may be fitted during assembly. VERIFY ON HARDWARE: purchased mating holes, connector cavities, polarity, voltage and load ratings are not inferred.

The final STEP controls shape and placement. Flat through-cut DXFs and individual part STEP files are included. Reference envelopes and schematic diagrams are not physical cutting parts. Purchased proxies are placement references, not manufacturer production drawings.

Detailed drawing index follows. PDF bookmarks and DRAWING_INDEX.csv use the same drawing numbers. Fabrication pages are dimensional source drawings; shaded CAD views support assembly understanding.

Complete drawing index | A-000-I1
V13-REISSUE-20260929 | 2026-09-29 | mm | A3 | fitted views: use written dimensions | SHEET 2 / 202
SHEET | DRAWING | TITLE
7 | A-001 | General assembly - major item balloons
8 | A-002 | Orthographic - FRONT / REAR
9 | A-003 | Orthographic - LEFT / RIGHT
10 | A-004 | Orthographic - TOP / BOTTOM
11 | A-005-1 | Major component positions / global coordinates
12 | A-005-2 | Major component positions / global coordinates
13 | A-005-3 | Major component positions / global coordinates
14 | A-006 | Exploded assembly - nine groups
15 | A-007-1 | Assembly groups 1 to 3
16 | A-007-2 | Assembly groups 4 to 6
17 | A-007-3 | Assembly groups 7 to 9
18 | A-008 | Frame assembly / rods / brackets
19 | F-101 | Fabrication - BOTTOM_PLATE
20 | F-101-H1 | Coordinate schedule - BOTTOM_PLATE
21 | F-101-H2 | Coordinate schedule - BOTTOM_PLATE
22 | F-101-H3 | Coordinate schedule - BOTTOM_PLATE
23 | F-101-H4 | Coordinate schedule - BOTTOM_PLATE
24 | F-101-H5 | Coordinate schedule - BOTTOM_PLATE
25 | F-102 | Fabrication - BATTERY_PLATE
26 | F-103 | Fabrication - CHASSIS_PAD_0_0
27 | F-104 | Fabrication - CHASSIS_PAD_0_1
28 | F-105 | Fabrication - CHASSIS_PAD_1_0
SHEET | DRAWING | TITLE
29 | F-106 | Fabrication - CHASSIS_PAD_1_1
30 | F-107 | Fabrication - CHASSIS_PAD_2_0
31 | F-108 | Fabrication - CHASSIS_PAD_2_1
32 | F-109 | Fabrication - CHASSIS_PAD_3_0
33 | F-110 | Fabrication - CHASSIS_PAD_3_1
34 | F-111 | Fabrication - ELECTRONICS_PLATE
35 | F-111-H1 | Coordinate schedule - ELECTRONICS_PLATE
36 | F-111-H2 | Coordinate schedule - ELECTRONICS_PLATE
37 | F-111-H3 | Coordinate schedule - ELECTRONICS_PLATE
38 | F-111-H4 | Coordinate schedule - ELECTRONICS_PLATE
39 | F-112 | Fabrication - LEFT_PANEL
40 | F-112-H1 | Coordinate schedule - LEFT_PANEL
41 | F-112-H2 | Coordinate schedule - LEFT_PANEL
42 | F-113 | Fabrication - RIGHT_PANEL
43 | F-113-H1 | Coordinate schedule - RIGHT_PANEL
44 | F-113-H2 | Coordinate schedule - RIGHT_PANEL
45 | F-114 | Fabrication - REAR_PANEL
46 | F-115 | Fabrication - FRONT_PANEL
47 | F-116 | Fabrication - LIDAR_BRIDGE
48 | F-117 | Fabrication - LIDAR_PLATE
49 | F-118 | Fabrication - JETSON_CRADLE
50 | F-119 | Fabrication - BATTERY_STOP_FRONT

Complete drawing index | A-000-I2
V13-REISSUE-20260929 | 2026-09-29 | mm | A3 | fitted views: use written dimensions | SHEET 3 / 202
SHEET | DRAWING | TITLE
51 | F-120 | Fabrication - BATTERY_STOP_REAR
52 | F-121 | Fabrication - BATTERY_STOP_LEFT
53 | F-122 | Fabrication - BATTERY_STOP_RIGHT
54 | F-123 | Fabrication - HUB_TRAY
55 | F-124 | Fabrication - POWER_BACKPLANE
56 | F-125 | Fabrication - FUSE_SHELF
57 | F-125-H1 | Coordinate schedule - FUSE_SHELF
58 | F-126 | Fabrication - BOOST_BASE
59 | F-127 | Fabrication - FUSEBLOCK_TRAY
60 | F-128 | Fabrication - JETSON_BASE_RETAINER_LEFT
61 | F-129 | Fabrication - JETSON_BASE_RETAINER_RIGHT
62 | F-130 | Fabrication - RELAY_TRAY
63 | F-131 | Fabrication - CAMERA_BASE
64 | F-132 | Fabrication - PAN_SERVO_MOUNT
65 | F-133 | Fabrication - PAN_YOKE
66 | F-134 | Fabrication - PAN_ARM_LEFT
67 | F-135 | Fabrication - CAM_L_LEFT
68 | F-136 | Fabrication - PAN_ARM_RIGHT
69 | F-137 | Fabrication - CAM_L_RIGHT
70 | F-138 | Fabrication - TILT_SERVO_MOUNT
71 | F-139 | Fabrication - TILT_CHEEK_LEFT
72 | F-140 | Fabrication - TILT_CHEEK_RIGHT
SHEET | DRAWING | TITLE
73 | F-141 | Fabrication - C920_SADDLE
74 | F-142 | Fabrication - TILT_CORNER_LEFT0
75 | F-143 | Fabrication - TILT_CORNER_LEFT1
76 | F-144 | Fabrication - TILT_CORNER_RIGHT0
77 | F-145 | Fabrication - TILT_CORNER_RIGHT1
78 | F-146 | Fabrication - TILT_BUSH_LEFT
79 | F-147 | Fabrication - THERMAL_MOUNT
80 | F-148 | Fabrication - THERMAL_ANGLE_0
81 | F-149 | Fabrication - THERMAL_ANGLE_1
82 | F-150 | Fabrication - THERMAL_EDGE_0
83 | F-151 | Fabrication - THERMAL_EDGE_1
84 | F-152 | Fabrication - FRONT_BUMPER
85 | F-153 | Fabrication - FRONT_STRIKER
86 | F-154 | Fabrication - FRONT_GUIDE_FOOT_0
87 | F-155 | Fabrication - FRONT_GUIDE_HANGER_0
88 | F-156 | Fabrication - FRONT_GUIDE_ANGLE_0
89 | F-157 | Fabrication - FRONT_GUIDE_BUSH_0
90 | F-158 | Fabrication - FRONT_STOPPER_0
91 | F-159 | Fabrication - FRONT_GUIDE_FOOT_1
92 | F-160 | Fabrication - FRONT_GUIDE_HANGER_1
93 | F-161 | Fabrication - FRONT_GUIDE_ANGLE_1
94 | F-162 | Fabrication - FRONT_GUIDE_BUSH_1

Complete drawing index | A-000-I3
V13-REISSUE-20260929 | 2026-09-29 | mm | A3 | fitted views: use written dimensions | SHEET 4 / 202
SHEET | DRAWING | TITLE
95 | F-163 | Fabrication - FRONT_STOPPER_1
96 | F-164 | Fabrication - FRONT_SWITCH_BRACKET
97 | F-165 | Fabrication - FRONT_SWITCH_FOOT
98 | F-166 | Fabrication - FRONT_SWITCH_ANGLE
99 | F-167 | Fabrication - FRONT_CORNER_NOSE_-1
100 | F-168 | Fabrication - FRONT_CORNER_NOSE_1
101 | F-169 | Fabrication - REAR_BUMPER
102 | F-170 | Fabrication - REAR_STRIKER
103 | F-171 | Fabrication - REAR_GUIDE_FOOT_0
104 | F-172 | Fabrication - REAR_GUIDE_HANGER_0
105 | F-173 | Fabrication - REAR_GUIDE_ANGLE_0
106 | F-174 | Fabrication - REAR_GUIDE_BUSH_0
107 | F-175 | Fabrication - REAR_STOPPER_0
108 | F-176 | Fabrication - REAR_GUIDE_FOOT_1
109 | F-177 | Fabrication - REAR_GUIDE_HANGER_1
110 | F-178 | Fabrication - REAR_GUIDE_ANGLE_1
111 | F-179 | Fabrication - REAR_GUIDE_BUSH_1
112 | F-180 | Fabrication - REAR_STOPPER_1
113 | F-181 | Fabrication - REAR_SWITCH_BRACKET
114 | F-182 | Fabrication - REAR_SWITCH_FOOT
115 | F-183 | Fabrication - REAR_SWITCH_ANGLE
116 | F-184 | Fabrication - REAR_CORNER_NOSE_-1
SHEET | DRAWING | TITLE
117 | F-185 | Fabrication - REAR_CORNER_NOSE_1
118 | F-186 | Fabrication - LEFT_BUMPER
119 | F-187 | Fabrication - LEFT_STRIKER
120 | F-188 | Fabrication - LEFT_GUIDE_FOOT_0
121 | F-189 | Fabrication - LEFT_GUIDE_HANGER_0
122 | F-190 | Fabrication - LEFT_GUIDE_ANGLE_0
123 | F-191 | Fabrication - LEFT_GUIDE_BUSH_0
124 | F-192 | Fabrication - LEFT_STOPPER_0
125 | F-193 | Fabrication - LEFT_GUIDE_FOOT_1
126 | F-194 | Fabrication - LEFT_GUIDE_HANGER_1
127 | F-195 | Fabrication - LEFT_GUIDE_ANGLE_1
128 | F-196 | Fabrication - LEFT_GUIDE_BUSH_1
129 | F-197 | Fabrication - LEFT_STOPPER_1
130 | F-198 | Fabrication - LEFT_SWITCH_BRACKET
131 | F-199 | Fabrication - LEFT_SWITCH_FOOT
132 | F-200 | Fabrication - LEFT_SWITCH_ANGLE
133 | F-201 | Fabrication - RIGHT_BUMPER
134 | F-202 | Fabrication - RIGHT_STRIKER
135 | F-203 | Fabrication - RIGHT_GUIDE_FOOT_0
136 | F-204 | Fabrication - RIGHT_GUIDE_HANGER_0
137 | F-205 | Fabrication - RIGHT_GUIDE_ANGLE_0
138 | F-206 | Fabrication - RIGHT_GUIDE_BUSH_0

Complete drawing index | A-000-I4
V13-REISSUE-20260929 | 2026-09-29 | mm | A3 | fitted views: use written dimensions | SHEET 5 / 202
SHEET | DRAWING | TITLE
139 | F-207 | Fabrication - RIGHT_STOPPER_0
140 | F-208 | Fabrication - RIGHT_GUIDE_FOOT_1
141 | F-209 | Fabrication - RIGHT_GUIDE_HANGER_1
142 | F-210 | Fabrication - RIGHT_GUIDE_ANGLE_1
143 | F-211 | Fabrication - RIGHT_GUIDE_BUSH_1
144 | F-212 | Fabrication - RIGHT_STOPPER_1
145 | F-213 | Fabrication - RIGHT_SWITCH_BRACKET
146 | F-214 | Fabrication - RIGHT_SWITCH_FOOT
147 | F-215 | Fabrication - RIGHT_SWITCH_ANGLE
148 | F-216 | Fabrication - ESP32_CARRIER
149 | F-217 | Fabrication - ESTOP_ADAPTER_RING
150 | F-218 | Fabrication - SPEAKER_MOUNT_0
151 | F-219 | Fabrication - SPEAKER_MOUNT_1
152 | F-220 | Fabrication - 5V_DISTRIBUTOR
153 | F-221 | Fabrication - ADC_CARRIER
154 | F-222 | Fabrication - HARNESS_CLAMP_0
155 | F-223 | Fabrication - HARNESS_CLAMP_1
156 | F-224 | Fabrication - HARNESS_CLAMP_2
157 | F-225 | Fabrication - HARNESS_CLAMP_3
158 | F-226 | Fabrication - HARNESS_CLAMP_4
159 | F-227 | Fabrication - HARNESS_CLAMP_5
160 | F-228 | Fabrication - HARNESS_CLAMP_6
SHEET | DRAWING | TITLE
161 | F-229 | Fabrication - HARNESS_CLAMP_7
162 | F-230 | Fabrication - TILT_HORN_COUPLER
163 | D-001 | Detail A - upper deck / M4 posts
164 | D-001-A | Detail A1 - deck clamp stack / rod cut lengths
165 | D-002 | Detail B - camera support fastening
166 | D-003 | Camera / thermal / Pan-Tilt - three views
167 | D-004 | Camera service loops / USB path
168 | D-005 | Detail C - LiDAR tower and scan reference
169 | D-006 | Detail D - FRONT limit switch / bumper
170 | D-007 | Detail D - REAR limit switch / bumper
171 | D-008 | Detail D - LEFT limit switch / bumper
172 | D-009 | Detail D - RIGHT limit switch / bumper
173 | D-010 | Detail E - battery mounting / removal
174 | E-201 | Power distribution component layout
175 | E-202 | Control / sensor component layout
176 | E-203 | Busbar / covered fuse box / rocker
177 | E-204 | Functional power diagram
178 | E-205 | Functional control / signal diagram
179 | E-206 | Physical cable routing - TOP
180 | E-207 | Physical cable routing - SIDE
181 | E-208 | Connector service access directions
182 | E-209 | Maintenance / service access

Complete drawing index | A-000-I5
V13-REISSUE-20260929 | 2026-09-29 | mm | A3 | fitted views: use written dimensions | SHEET 6 / 202
SHEET | DRAWING | TITLE
183 | E-211 | Electrical interface verification / open hardware items
184 | E-210-1 | Cable / connection schedule
185 | E-210-2 | Cable / connection schedule
186 | E-210-3 | Cable / connection schedule
187 | B-001-1 | BOM / drawing references
188 | B-001-2 | BOM / drawing references
189 | B-001-3 | BOM / drawing references
190 | B-001-4 | BOM / drawing references
191 | B-001-5 | BOM / drawing references
192 | B-001-6 | BOM / drawing references
193 | B-001-7 | BOM / drawing references
194 | B-001-8 | BOM / drawing references
195 | B-001-9 | BOM / drawing references
196 | B-001-10 | BOM / drawing references
197 | B-001-11 | BOM / drawing references
198 | B-001-12 | BOM / drawing references
199 | B-002-1 | Fastener list / model counts
200 | B-002-2 | Fastener list / model counts
201 | Q-001 | Fabrication and assembly sequence
202 | Q-002 | Pre-fabrication / commissioning checklist
SHEET | DRAWING | TITLE

General assembly - major item balloons | A-001

Item numbers link to BOM and location tables. Purchased assemblies are gray; fabricated supports are light. CAD axes and physical component positions are unchanged.

Orthographic - FRONT / REAR | A-002

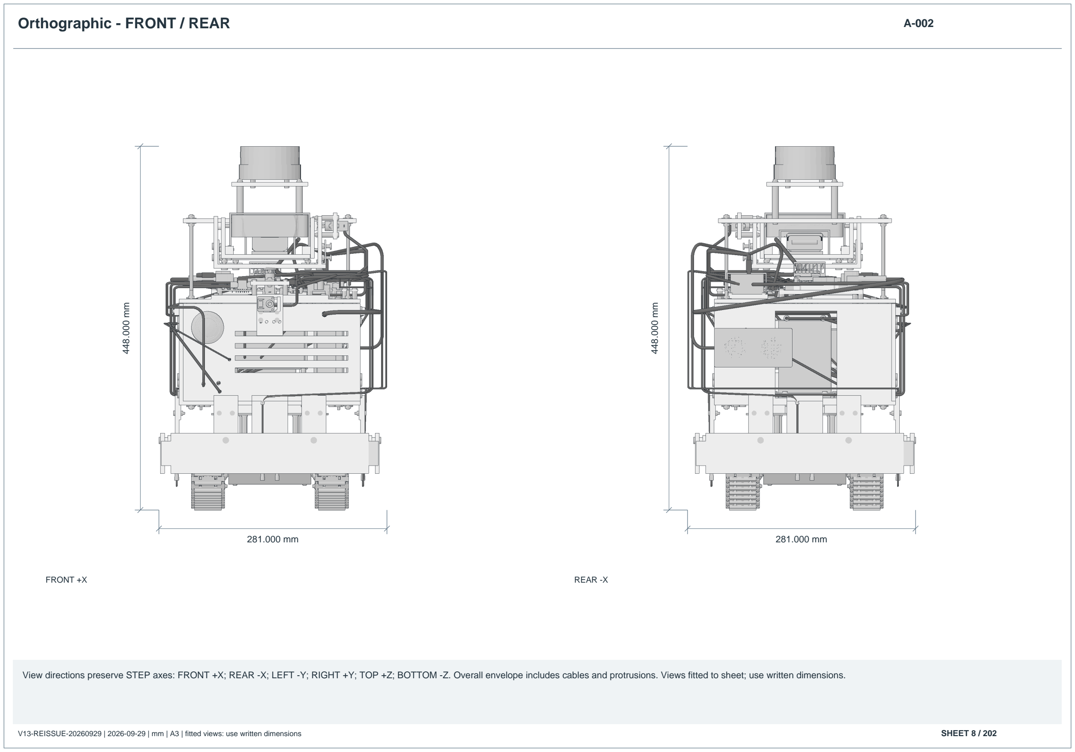
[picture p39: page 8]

V13-REISSUE-20260929 | 2026-09-29 | mm | A3 | fitted views: use written dimensions | SHEET 8 / 202

FRONT +X

281.000 mm

448.000 mm

REAR -X

281.000 mm

448.000 mm

View directions preserve STEP axes: FRONT +X; REAR -X; LEFT -Y; RIGHT +Y; TOP +Z; BOTTOM -Z. Overall envelope includes cables and protrusions. Views fitted to sheet; use written dimensions.

Orthographic - LEFT / RIGHT | A-003

V13-REISSUE-20260929 | 2026-09-29 | mm | A3 | fitted views: use written dimensions | SHEET 9 / 202

LEFT -Y

369.300 mm

448.000 mm

RIGHT +Y

369.300 mm

448.000 mm

View directions preserve STEP axes: FRONT +X; REAR -X; LEFT -Y; RIGHT +Y; TOP +Z; BOTTOM -Z. Overall envelope includes cables and protrusions. Views fitted to sheet; use written dimensions.

Orthographic - TOP / BOTTOM | A-004

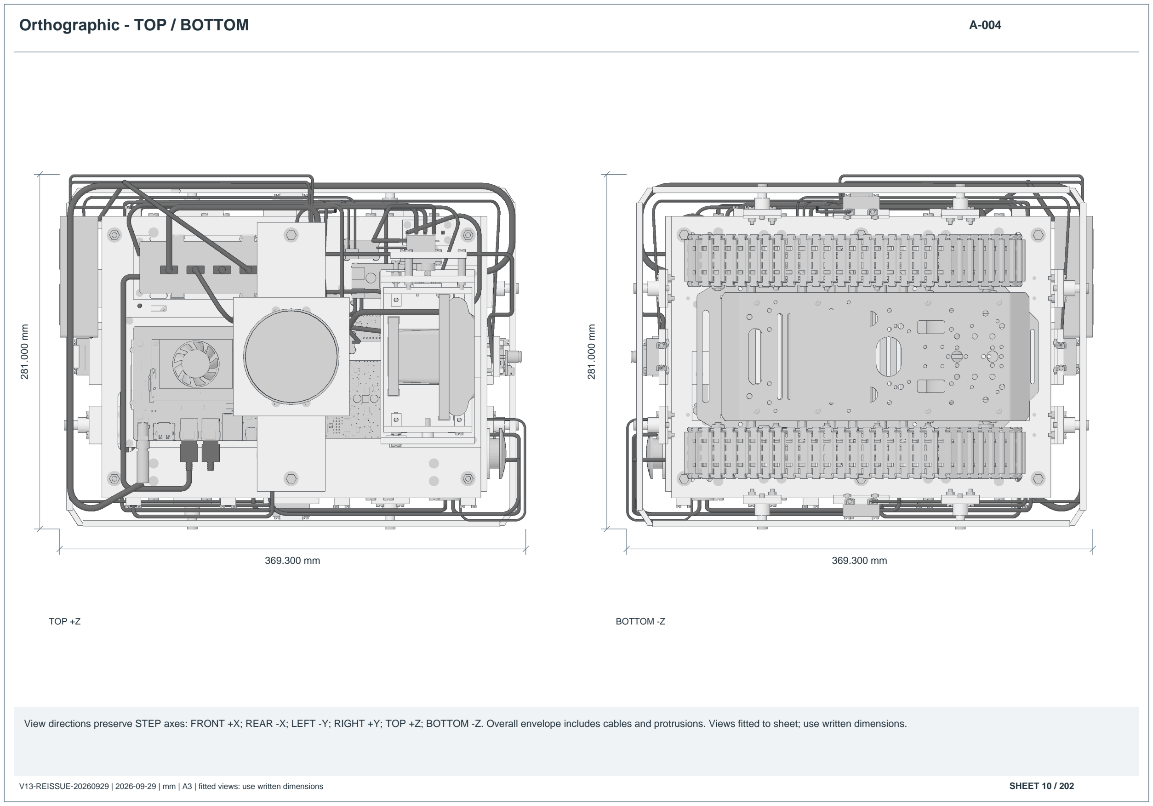
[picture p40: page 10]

V13-REISSUE-20260929 | 2026-09-29 | mm | A3 | fitted views: use written dimensions | SHEET 10 / 202

TOP +Z

369.300 mm

281.000 mm

BOTTOM -Z

369.300 mm

281.000 mm

View directions preserve STEP axes: FRONT +X; REAR -X; LEFT -Y; RIGHT +Y; TOP +Z; BOTTOM -Z. Overall envelope includes cables and protrusions. Views fitted to sheet; use written dimensions.

Major component positions / global coordinates | A-005-1
V13-REISSUE-20260929 | 2026-09-29 | mm | A3 | fitted views: use written dimensions | SHEET 11 / 202
ITEM | PART | MIN XYZ | MAX XYZ | ORIENTATION / DATUM
001 | Hiwonder tracked chassis | 0.00, -0.00, 0.00 | 279.94, 193.43, 121.62 | Global XYZ; orientation shown in A/D views
002 | NVIDIA Jetson Orin Nano | 15.00, 30.00, 271.00 | 118.00, 120.88, 305.77 | Global XYZ; orientation shown in A/D views
003 | Logitech C920 | 216.50, 49.72, 319.00 | 285.01, 143.71, 363.50 | Global XYZ; orientation shown in A/D views
004 | MLX90640 Thermal Camera HAT | 305.00, 81.62, 245.00 | 322.50, 101.77, 263.17 | Global XYZ; orientation shown in A/D views
005 | RPLIDAR A2M12 | 101.97, 58.72, 407.00 | 177.97, 134.72, 448.00 | Global XYZ; orientation shown in A/D views
006 | ESP32 DevKit 38-pin | 121.90, 122.66, 261.61 | 177.77, 149.34, 274.80 | Global XYZ; orientation shown in A/D views
007 | Cytron MDD10A Rev2 | 135.00, 32.00, 268.07 | 219.58, 93.72, 282.97 | Global XYZ; orientation shown in A/D views
008 | Adafruit BNO085 | 191.00, 109.00, 270.00 | 216.40, 131.86, 274.53 | Global XYZ; orientation shown in A/D views
009 | ROCKET ES7-12 AGM battery | 60.00, 64.00, 139.39 | 211.00, 129.00, 237.39 | Global XYZ; orientation shown in A/D views
010 | SZH-JA020 covered fuse box | 222.50, 53.00, 180.00 | 275.50, 139.00, 222.00 | Global XYZ; orientation shown in A/D views
011 | FHAC main fuse holder | 53.00, 14.00, 215.00 | 103.00, 35.20, 230.00 | Global XYZ; orientation shown in A/D views
012 | FHAC motor fuse holder | 119.00, 14.00, 215.00 | 169.00, 35.20, 230.00 | Global XYZ; orientation shown in A/D views
013 | 12V relay / socket | 228.00, 12.00, 164.00 | 262.00, 49.40, 200.00 | Global XYZ; orientation shown in A/D views
014 | Positive busbar | 70.00, 10.00, 148.00 | 168.00, 21.00, 165.00 | Global XYZ; orientation shown in A/D views
015 | Negative busbar | 70.00, 10.00, 177.00 | 168.00, 21.00, 194.00 | Global XYZ; orientation shown in A/D views
016 | SZH-EK366 5V converter | 187.92, 143.00, 270.00 | 251.40, 170.50, 282.60 | Global XYZ; orientation shown in A/D views

Coordinates are final assembly bounding positions, not mounting-hole locations. Use the matching fabrication detail and source mating geometry for installation. No part has been repositioned for these views.

Major component positions / global coordinates | A-005-2
V13-REISSUE-20260929 | 2026-09-29 | mm | A3 | fitted views: use written dimensions | SHEET 12 / 202
ITEM | PART | MIN XYZ | MAX XYZ | ORIENTATION / DATUM
017 | 12V to19V boost converter | 137.00, 155.00, 151.00 | 212.00, 186.00, 229.00 | Global XYZ; orientation shown in A/D views
018 | KGE-N&H E-STOP | 233.43, -0.00, 205.00 | 310.13, 40.00, 246.80 | Global XYZ; orientation shown in A/D views
019 | Main rocker switch | 255.00, -17.00, 220.00 | 275.00, -10.00, 240.00 | Global XYZ; orientation shown in A/D views
020 | USB speaker SP001 envelope | -43.50, 112.00, 176.00 | -13.00, 208.00, 224.00 | Global XYZ; orientation shown in A/D views
021 | Battery voltage divider | 182.00, 174.00, 270.00 | 209.00, 189.00, 280.10 | Global XYZ; orientation shown in A/D views
022 | NEXT505UHP USB hub | 20.00, 147.00, 266.00 | 121.00, 188.00, 291.00 | Global XYZ; orientation shown in A/D views
023 | MG90S pan servo | 226.53, 90.46, 263.75 | 258.73, 102.79, 296.00 | Global XYZ; orientation shown in A/D views
024 | MG90S tilt servo | 226.52, 160.72, 343.75 | 258.73, 192.97, 356.08 | Global XYZ; orientation shown in A/D views
025 | Pan horn | 240.00, 88.72, 296.00 | 256.00, 104.72, 298.00 | Global XYZ; orientation shown in A/D views
026 | Tilt horn | 240.00, 158.72, 342.00 | 256.00, 160.72, 358.00 | Global XYZ; orientation shown in A/D views
027 | LS-F FRONT V-J166 | 296.94, 82.22, 56.00 | 311.94, 111.22, 80.50 | Global XYZ; orientation shown in A/D views
028 | LS-R REAR V-J166 | -32.00, 82.22, 56.00 | -17.00, 111.22, 80.50 | Global XYZ; orientation shown in A/D views
029 | LS-L LEFT V-J166 | 125.47, -32.00, 56.00 | 154.47, -17.00, 80.50 | Global XYZ; orientation shown in A/D views
030 | LS-Rt RIGHT V-J166 | 125.47, 210.43, 56.00 | 154.47, 225.43, 80.50 | Global XYZ; orientation shown in A/D views
031 | WD SN530 2242 SSD | 48.00, 63.00, 268.00 | 70.00, 105.00, 270.70 | Global XYZ; orientation shown in A/D views
032 | ADC carrier / hardware VERIFY | 221.00, 117.00, 265.00 | 262.00, 142.00, 267.00 | Global XYZ; orientation shown in A/D views

Coordinates are final assembly bounding positions, not mounting-hole locations. Use the matching fabrication detail and source mating geometry for installation. No part has been repositioned for these views.

Major component positions / global coordinates | A-005-3
V13-REISSUE-20260929 | 2026-09-29 | mm | A3 | fitted views: use written dimensions | SHEET 13 / 202
ITEM | PART | MIN XYZ | MAX XYZ | ORIENTATION / DATUM
033 | Encoder level interface | 166.00, 100.00, 270.00 | 190.00, 116.00, 273.10 | Global XYZ; orientation shown in A/D views

Coordinates are final assembly bounding positions, not mounting-hole locations. Use the matching fabrication detail and source mating geometry for installation. No part has been repositioned for these views.

Exploded assembly - nine groups | A-006

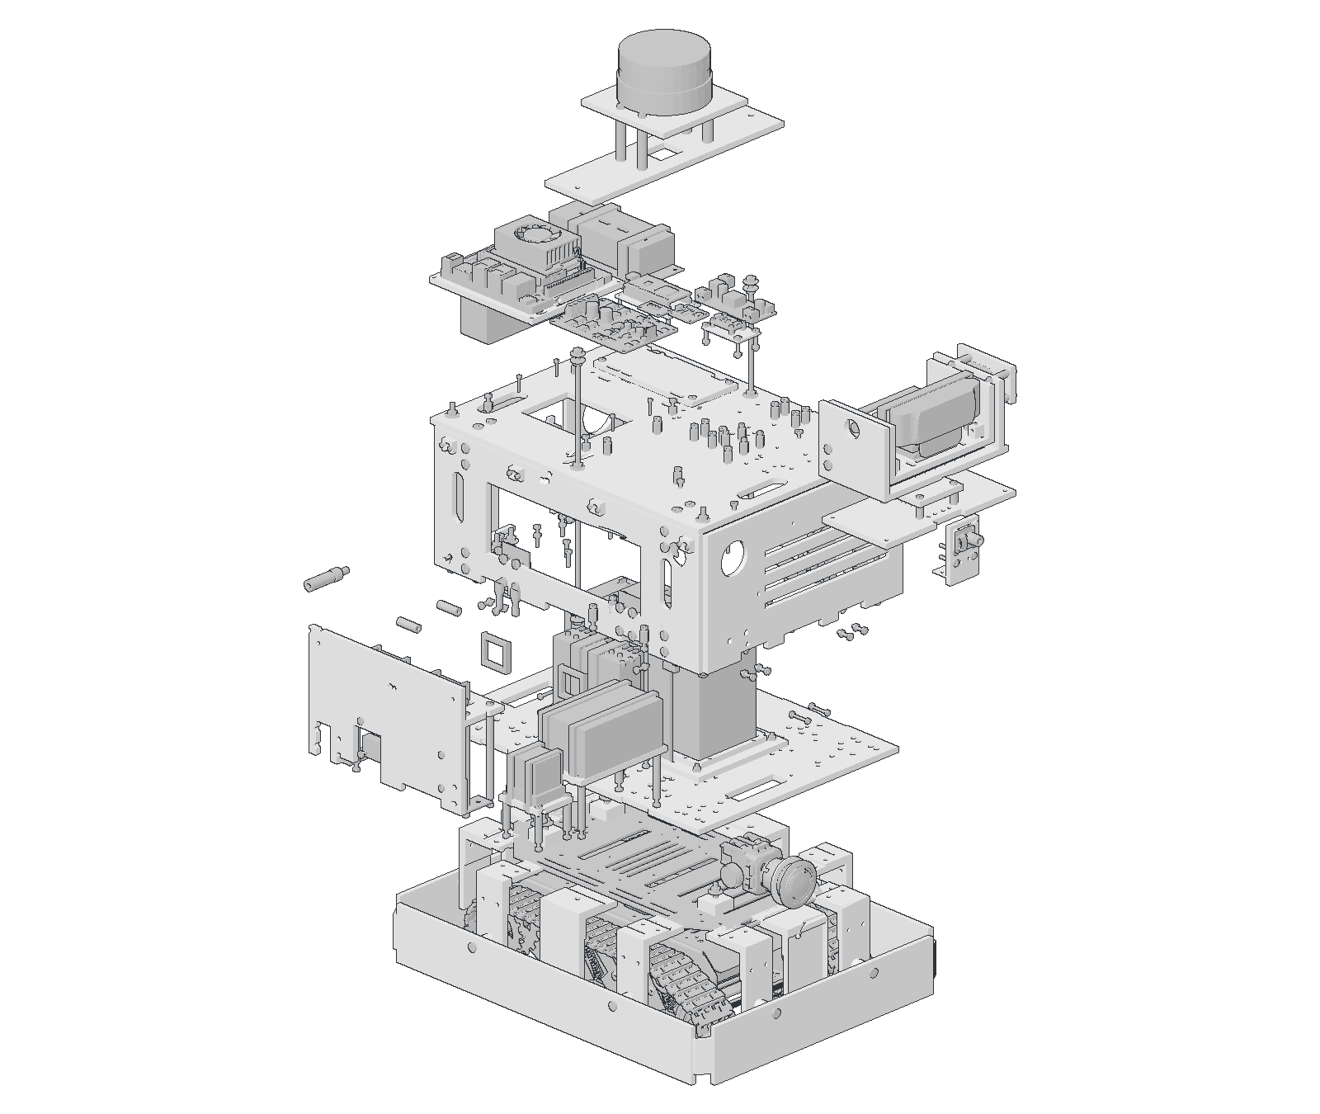
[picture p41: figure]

V13-REISSUE-20260929 | 2026-09-29 | mm | A3 | fitted views: use written dimensions | SHEET 14 / 202

## EXPLODED VIEW Display offsets only. Final assembly coordinates

remain unchanged.

### 1 Chassis

### 2 Lower frame / battery

### 3 Upper deck / posts

### 4 Compute / control

### 5 Power distribution

### 6 LiDAR tower

### 7 Camera / thermal / Pan-Tilt

### 8 E-STOP / rocker

### 9 Four bumper / switch modules

Remove electrical connections and retainers before separating modules. Assemble lower frame first; install power and battery before closing upper deck. Side panels and bumper modules attach laterally; top sensor modules lift off after their fasteners are removed.

Assembly groups 1 to 3 | A-007-1

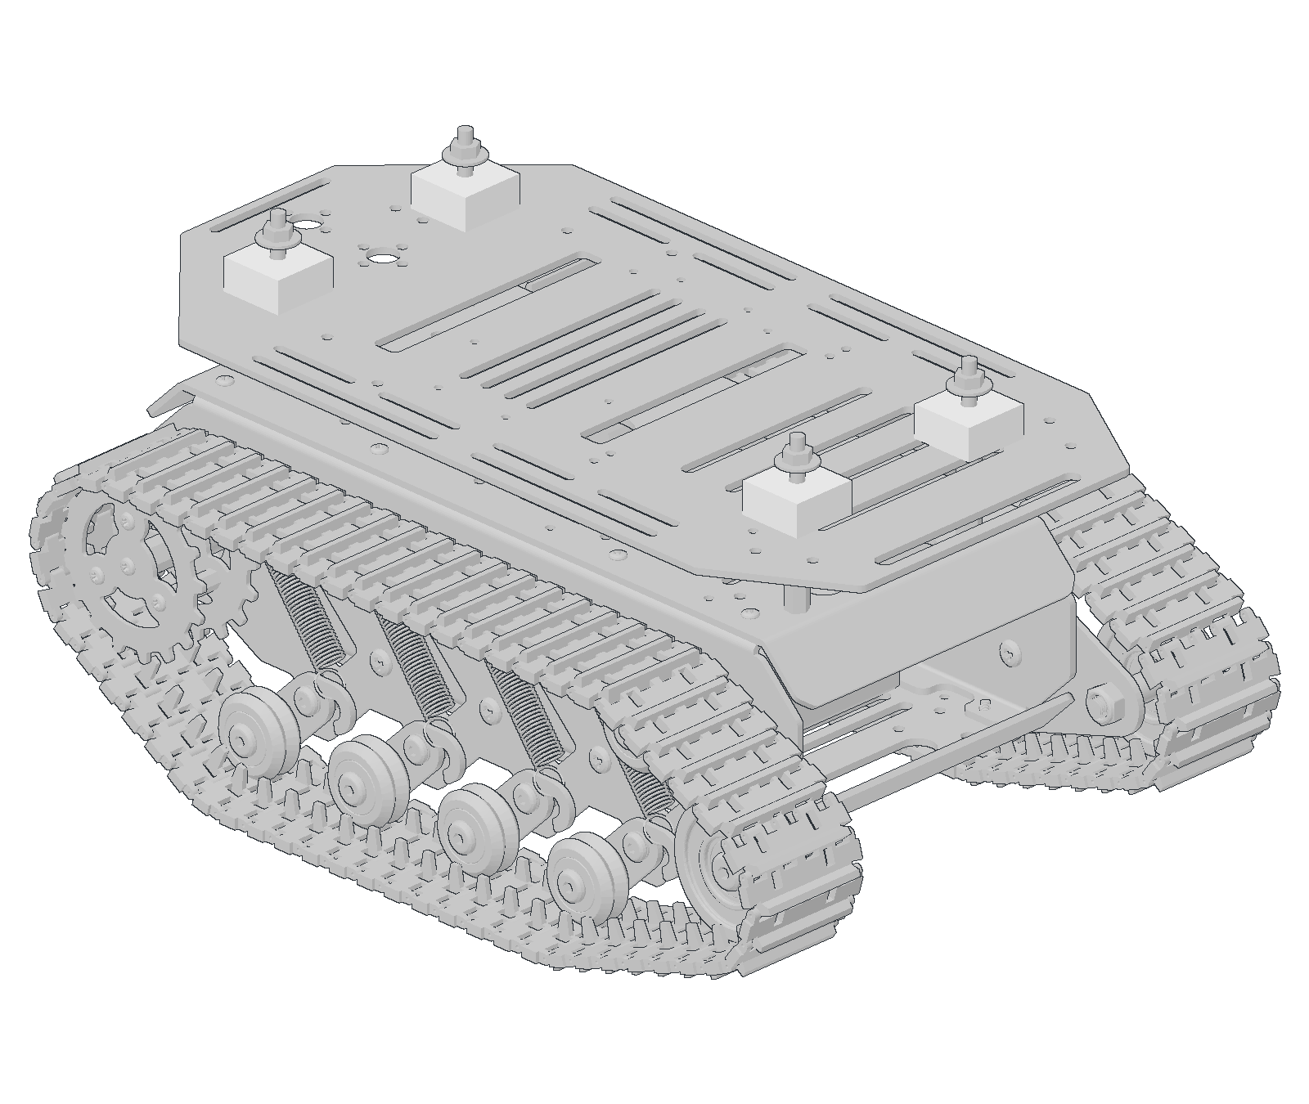
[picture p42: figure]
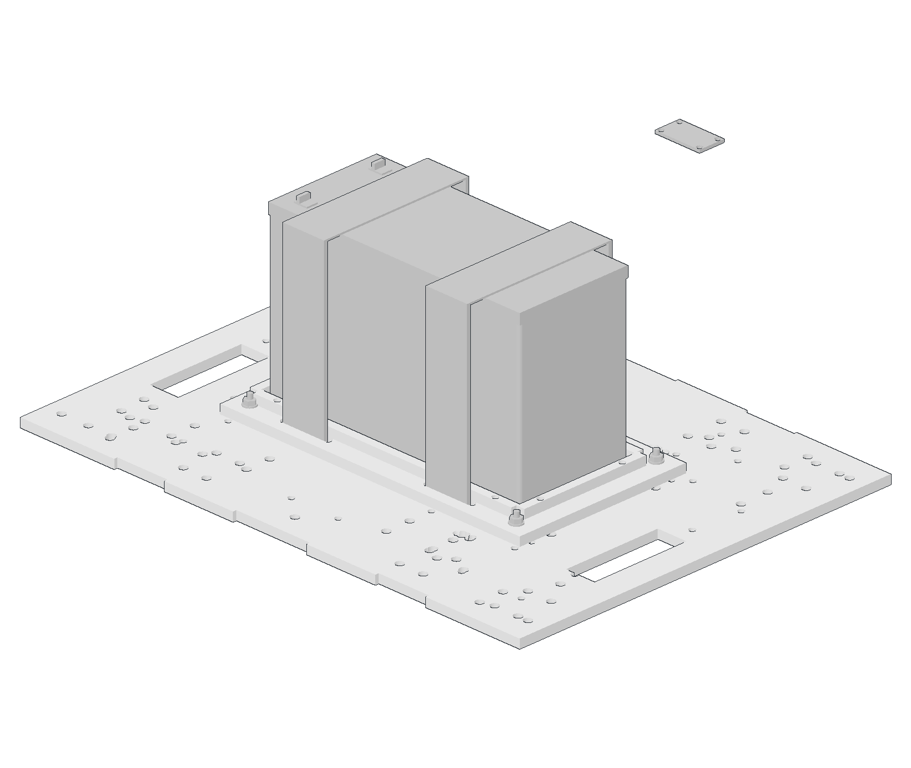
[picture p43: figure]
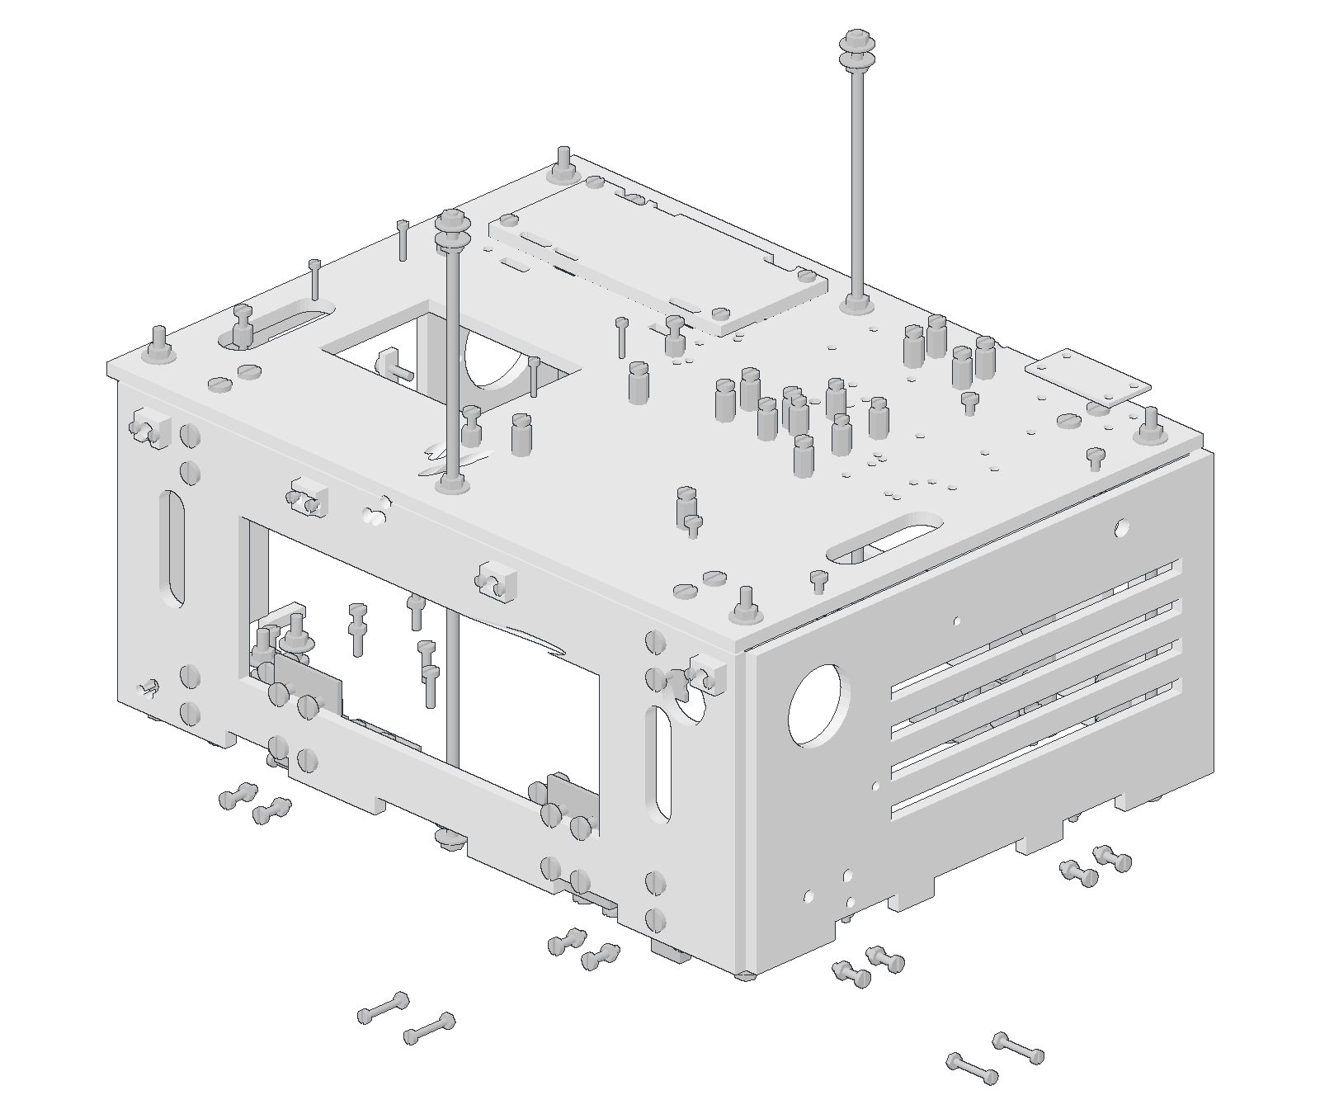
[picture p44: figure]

V13-REISSUE-20260929 | 2026-09-29 | mm | A3 | fitted views: use written dimensions | SHEET 15 / 202

1 Chassis

### Keep supplied chassis subassembly intact; mount pads and lower

plate above the existing top plate.

Assembly order 1

2 Lower frame / battery

### Battery sits on its support plate between stops; straps restrain the

case. Keep terminals accessible before upper deck closure.

Assembly order 2

3 Upper deck / posts

M4 rods locate lower and upper plates. L brackets tie panels to plates; washers spread load on sheet.

Assembly order 3

These views isolate groups for visibility; geometry and orientation within each group are unchanged. All actual fastener / plate references remain available in the part STEP files and BOM mapping.

Assembly groups 4 to 6 | A-007-2

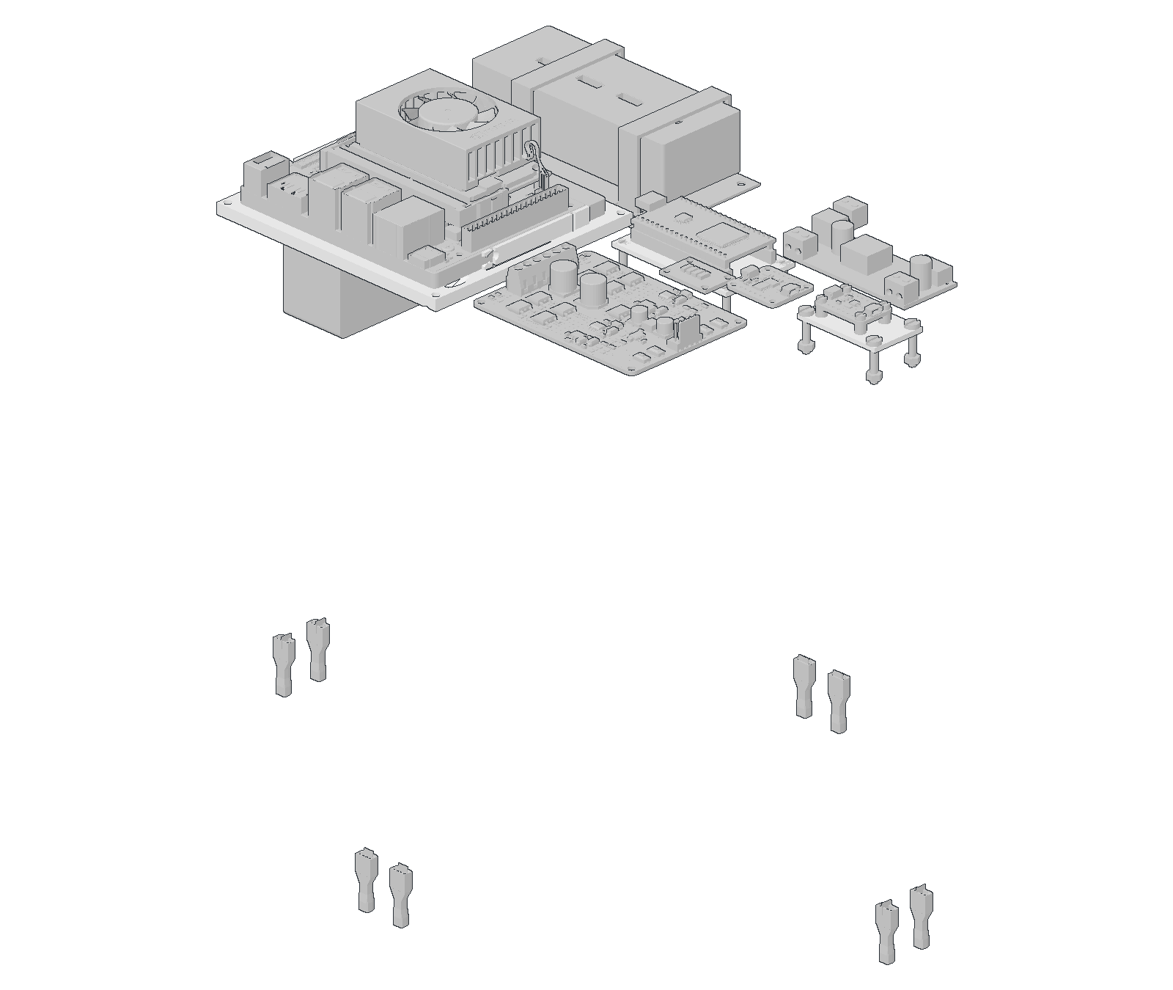
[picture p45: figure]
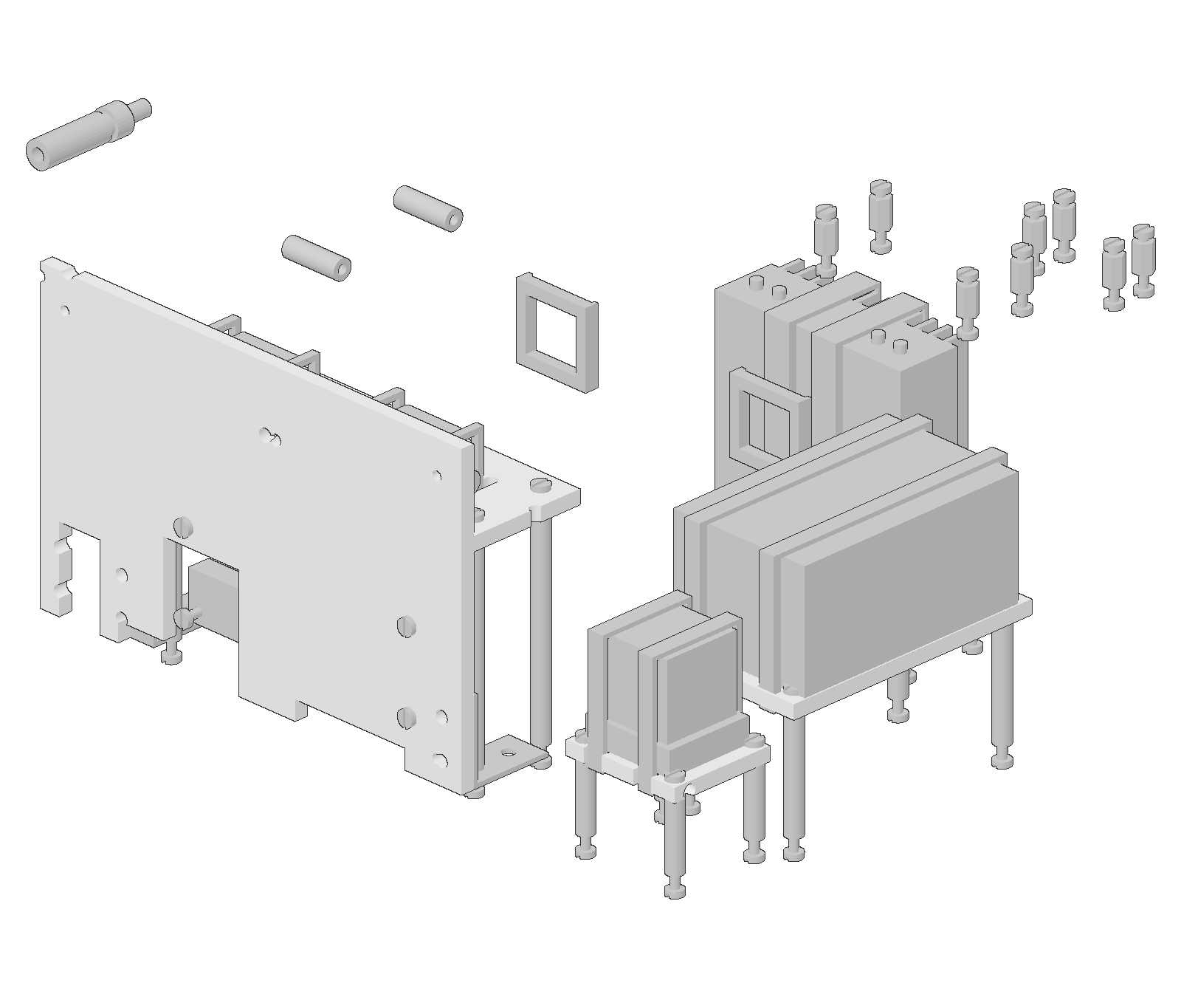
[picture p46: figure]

V13-REISSUE-20260929 | 2026-09-29 | mm | A3 | fitted views: use written dimensions | SHEET 16 / 202

4 Compute / control

### Use the documented carrier / cradle and M3 standoffs. USB and

terminal faces retain final STEP orientations.

Assembly order 4

5 Power distribution

### Install backplane, busbars, covered fuse box, relay and converters

before closing side walls.

Assembly order 5

6 LiDAR tower

M3 through-bolts pass bridge and40mm risers to the sensor plate. Top removal direction +Z.

Assembly order 6

These views isolate groups for visibility; geometry and orientation within each group are unchanged. All actual fastener / plate references remain available in the part STEP files and BOM mapping.

Assembly groups 7 to 9 | A-007-3

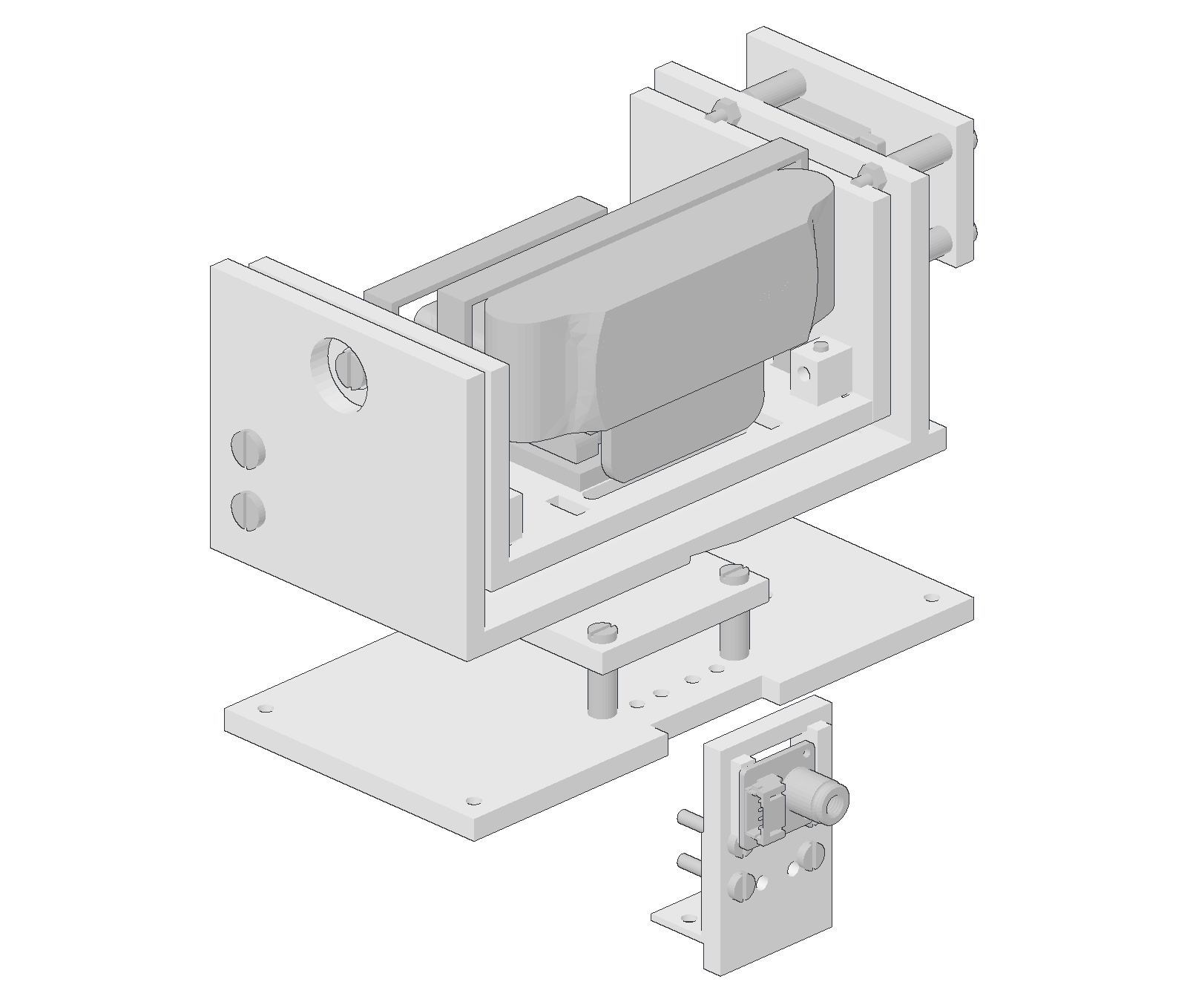
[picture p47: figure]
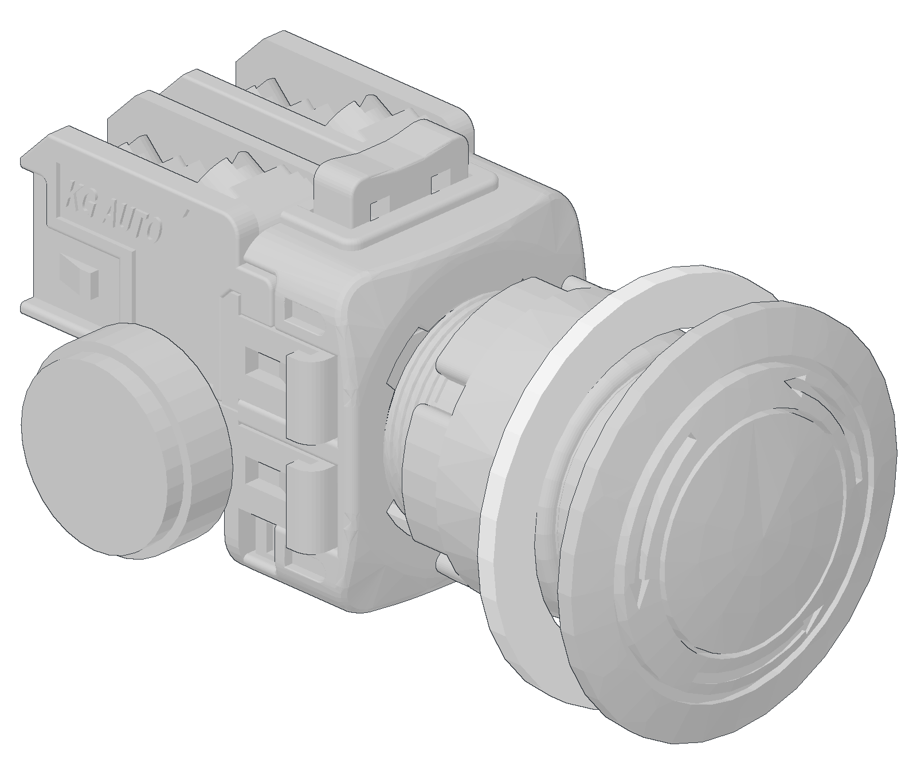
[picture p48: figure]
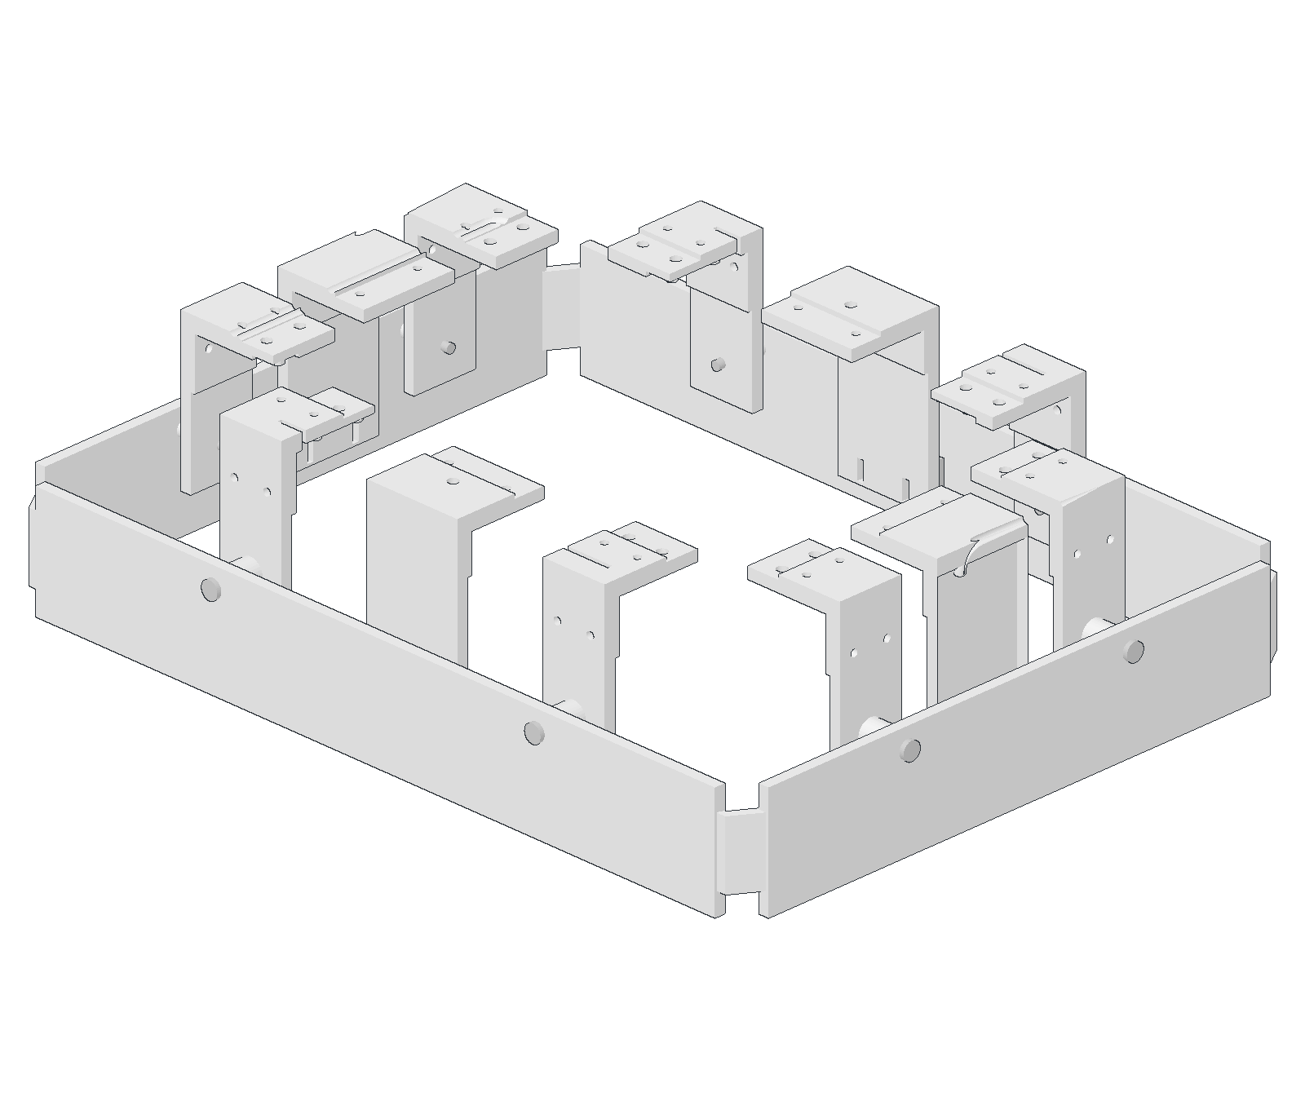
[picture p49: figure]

V13-REISSUE-20260929 | 2026-09-29 | mm | A3 | fitted views: use written dimensions | SHEET 17 / 202

7 Camera / thermal / Pan-Tilt

Build the pan base, yoke, tilt frame and camera saddle as a module. Fit the thermal board to the front wall.

Assembly order 7

8 E-STOP / rocker

### Rocker actuator is outward-facing; E-STOP head remains externally

accessible. Terminal work requires panel access.

Assembly order 8

9 Four bumper / switch modules

Each bumper pushes its named lever through the modeled striker. Release must return under spring action.

Assembly order 9

These views isolate groups for visibility; geometry and orientation within each group are unchanged. All actual fastener / plate references remain available in the part STEP files and BOM mapping.

Frame assembly / rods / brackets | A-008

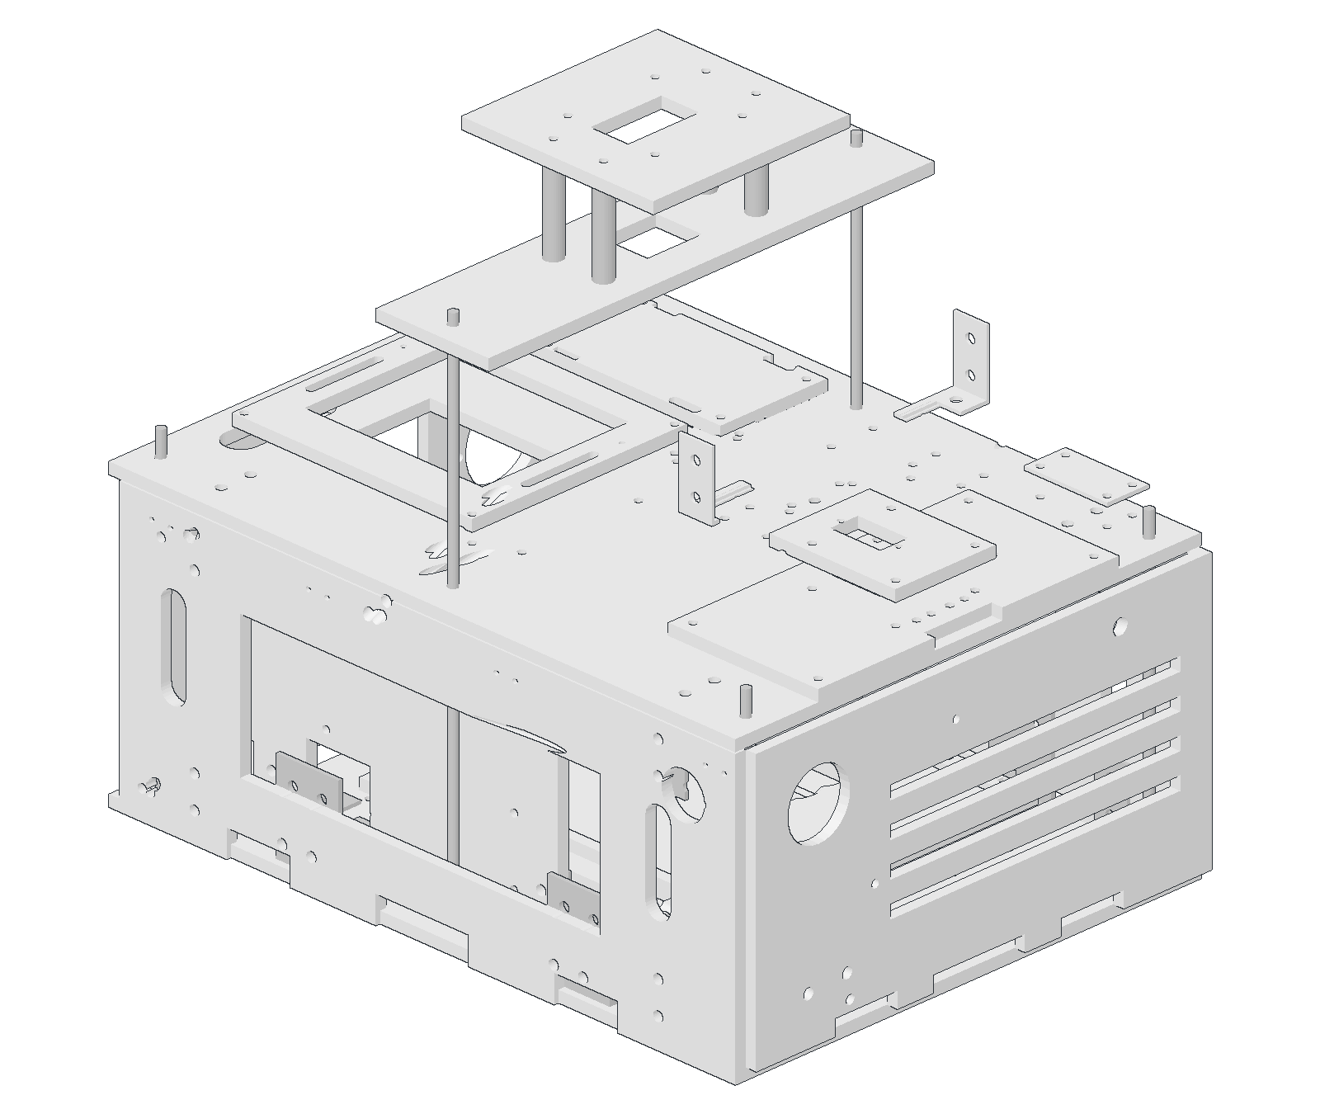
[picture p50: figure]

V13-REISSUE-20260929 | 2026-09-29 | mm | A3 | fitted views: use written dimensions | SHEET 18 / 202

## FRAME RELATIONSHIPS

### 01. Lower plate is located on the chassis pads; keep existing chassis

mounting interfaces.

### 02. M4 rods pass lower and upper plate holes. Washers spread load

on foam/PVC sheet; nuts lock plate height.

### 03. L brackets connect panels/plates; their measured stock hole

pattern remains VERIFY ON HARDWARE.

### 04. M3 PCB standoffs support the electronic carriers. Straps retain

battery and larger housings.

Use final STEP part relationships and the matching F drawing. Standard hardware heads / holes are nominal; verify purchased fasteners, clamp load and tool access on hardware.

Fabrication - BOTTOM_PLATE | F-101

## CUSTOM_BOTTOM_PLATE

Qty1 | PVC foam / Fomex | thickness/depth 5.000 mm

Full XY schedule follows; cross marks locate centers.

SIDE EDGE PROJECTION - X / DEPTH

Assembly datum XYZ: -10.000, -15.000, 129.390

VERIFIED CAD NOMINAL: geometry measured from the final model; hardware interfaces may require ASSEMBLY ADJUST.

DXF through-cut profile supplied; units mm, arc tolerance0.01; no kerf allowance.

Coordinate schedule - BOTTOM_PLATE | F-101-H1
V13-REISSUE-20260929 | 2026-09-29 | mm | A3 | fitted views: use written dimensions | SHEET 20 / 202
ID | FEATURE | X from A | Y from B | DIA | WIDTH | HEIGHT
H01 | HOLE | 263.000 | 13.000 | 4.500 | 4.500 | 4.500
H02 | CUTOUT | 40.500 | 14.000 | - | 5.500 | 6.500
H03 | HOLE | 10.000 | 15.000 | 4.500 | 4.500 | 4.500
H04 | HOLE | 26.000 | 15.000 | 4.500 | 4.500 | 4.500
H05 | HOLE | 83.000 | 15.000 | 4.500 | 4.500 | 4.500
H06 | HOLE | 97.000 | 15.000 | 4.500 | 4.500 | 4.500
H07 | HOLE | 149.970 | 15.000 | 4.500 | 4.500 | 4.500
H08 | HOLE | 213.000 | 15.000 | 4.500 | 4.500 | 4.500
H09 | HOLE | 227.000 | 15.000 | 4.500 | 4.500 | 4.500
H10 | HOLE | 270.000 | 15.000 | 4.500 | 4.500 | 4.500
H11 | HOLE | 284.000 | 15.000 | 4.500 | 4.500 | 4.500
H12 | HOLE | 290.000 | 15.000 | 4.500 | 4.500 | 4.500
H13 | HOLE | 41.000 | 27.000 | 4.500 | 4.500 | 4.500
H14 | HOLE | 135.970 | 27.000 | 3.400 | 3.400 | 3.400
H15 | HOLE | 163.970 | 27.000 | 3.400 | 3.400 | 3.400
H16 | HOLE | 263.000 | 27.000 | 4.500 | 4.500 | 4.500
H17 | HOLE | 273.000 | 28.000 | 3.400 | 3.400 | 3.400
H18 | CUTOUT | 236.401 | 29.275 | - | 4.597 | 5.950
H19 | HOLE | 79.587 | 30.000 | 4.500 | 4.500 | 4.500
H20 | HOLE | 220.353 | 30.000 | 4.500 | 4.500 | 4.500
H21 | CUTOUT | 64.018 | 31.225 | - | 5.363 | 6.950
H22 | HOLE | 33.000 | 33.000 | 4.500 | 4.500 | 4.500

Same datum as F-101. Dimensions are CAD nominal. Noncircular width/height are feature bounding dimensions; the STEP / supplied DXF controls the actual contour.

Coordinate schedule - BOTTOM_PLATE | F-101-H2
V13-REISSUE-20260929 | 2026-09-29 | mm | A3 | fitted views: use written dimensions | SHEET 21 / 202
ID | FEATURE | X from A | Y from B | DIA | WIDTH | HEIGHT
H23 | HOLE | 58.000 | 33.000 | 4.500 | 4.500 | 4.500
H24 | HOLE | 103.000 | 33.000 | 4.600 | 4.600 | 4.600
H25 | HOLE | 187.000 | 33.000 | 4.500 | 4.500 | 4.500
H26 | CUTOUT | 213.000 | 33.975 | - | 4.600 | 6.550
H27 | HOLE | 26.000 | 35.000 | 4.500 | 4.500 | 4.500
H28 | HOLE | 40.000 | 35.000 | 4.500 | 4.500 | 4.500
H29 | HOLE | 83.000 | 35.000 | 4.500 | 4.500 | 4.500
H30 | HOLE | 97.000 | 35.000 | 4.500 | 4.500 | 4.500
H31 | HOLE | 227.000 | 35.000 | 4.500 | 4.500 | 4.500
H32 | HOLE | 270.000 | 35.000 | 4.500 | 4.500 | 4.500
H33 | HOLE | 284.000 | 35.000 | 4.500 | 4.500 | 4.500
H34 | HOLE | 33.000 | 47.000 | 4.500 | 4.500 | 4.500
H35 | HOLE | 58.000 | 47.000 | 4.500 | 4.500 | 4.500
H36 | HOLE | 103.000 | 47.000 | 4.600 | 4.600 | 4.600
H37 | HOLE | 187.000 | 47.000 | 4.500 | 4.500 | 4.500
H38 | HOLE | 213.000 | 47.000 | 4.600 | 4.600 | 4.600
H39 | HOLE | 25.000 | 49.555 | 4.500 | 4.500 | 4.500
H40 | HOLE | 274.939 | 49.555 | 4.500 | 4.500 | 4.500
H41 | CUTOUT | 213.925 | 53.511 | - | 10.650 | 5.821
H42 | HOLE | 65.000 | 60.000 | 3.400 | 3.400 | 3.400
H43 | HOLE | 187.000 | 60.000 | 3.400 | 3.400 | 3.400
H44 | HOLE | 237.000 | 60.000 | 3.400 | 3.400 | 3.400

Same datum as F-101. Dimensions are CAD nominal. Noncircular width/height are feature bounding dimensions; the STEP / supplied DXF controls the actual contour.

Coordinate schedule - BOTTOM_PLATE | F-101-H3
V13-REISSUE-20260929 | 2026-09-29 | mm | A3 | fitted views: use written dimensions | SHEET 22 / 202
ID | FEATURE | X from A | Y from B | DIA | WIDTH | HEIGHT
H45 | HOLE | 238.000 | 69.000 | 3.400 | 3.400 | 3.400
H46 | HOLE | 68.000 | 70.000 | 3.400 | 3.400 | 3.400
H47 | SLOT | 102.000 | 70.000 | - | 30.000 | 4.000
H48 | SLOT | 188.000 | 70.000 | - | 30.000 | 4.000
H49 | HOLE | 228.000 | 70.000 | 3.400 | 3.400 | 3.400
H50 | HOLE | 51.625 | 77.648 | 4.500 | 4.500 | 4.500
H51 | HOLE | 238.438 | 80.433 | 4.500 | 4.500 | 4.500
H52 | SLOT | 275.500 | 87.150 | - | 17.000 | 57.700
H53 | CUTOUT | 25.500 | 88.500 | - | 17.000 | 55.000
H54 | HOLE | 22.000 | 125.715 | 3.400 | 3.400 | 3.400
H55 | HOLE | 277.939 | 125.715 | 3.400 | 3.400 | 3.400
H56 | HOLE | 238.438 | 143.180 | 4.500 | 4.500 | 4.500
H57 | HOLE | 51.625 | 145.965 | 4.500 | 4.500 | 4.500
H58 | SLOT | 102.000 | 153.000 | - | 30.000 | 4.000
H59 | SLOT | 188.000 | 153.000 | - | 30.000 | 4.000
H60 | HOLE | 238.000 | 153.000 | 3.400 | 3.400 | 3.400
H61 | HOLE | 280.000 | 153.000 | 3.400 | 3.400 | 3.400
H62 | HOLE | 68.000 | 154.000 | 3.400 | 3.400 | 3.400
H63 | HOLE | 228.000 | 154.000 | 3.400 | 3.400 | 3.400
H64 | HOLE | 25.000 | 157.875 | 4.500 | 4.500 | 4.500
H65 | HOLE | 274.939 | 157.875 | 4.500 | 4.500 | 4.500
H66 | HOLE | 169.000 | 159.000 | 3.400 | 3.400 | 3.400

Same datum as F-101. Dimensions are CAD nominal. Noncircular width/height are feature bounding dimensions; the STEP / supplied DXF controls the actual contour.

Coordinate schedule - BOTTOM_PLATE | F-101-H4
V13-REISSUE-20260929 | 2026-09-29 | mm | A3 | fitted views: use written dimensions | SHEET 23 / 202
ID | FEATURE | X from A | Y from B | DIA | WIDTH | HEIGHT
H67 | HOLE | 245.000 | 159.000 | 3.400 | 3.400 | 3.400
H68 | CUTOUT | 213.925 | 169.825 | - | 10.650 | 5.150
H69 | HOLE | 146.000 | 172.000 | 3.400 | 3.400 | 3.400
H70 | HOLE | 222.000 | 172.000 | 3.400 | 3.400 | 3.400
H71 | HOLE | 25.000 | 173.875 | 4.500 | 4.500 | 4.500
H72 | HOLE | 274.939 | 173.875 | 4.500 | 4.500 | 4.500
H73 | HOLE | 169.000 | 186.000 | 3.400 | 3.400 | 3.400
H74 | HOLE | 245.000 | 186.000 | 3.400 | 3.400 | 3.400
H75 | HOLE | 26.000 | 188.000 | 4.500 | 4.500 | 4.500
H76 | HOLE | 40.000 | 188.000 | 4.500 | 4.500 | 4.500
H77 | HOLE | 83.000 | 188.000 | 4.500 | 4.500 | 4.500
H78 | HOLE | 97.000 | 188.000 | 4.500 | 4.500 | 4.500
H79 | HOLE | 213.000 | 188.000 | 4.500 | 4.500 | 4.500
H80 | HOLE | 227.000 | 188.000 | 4.500 | 4.500 | 4.500
H81 | HOLE | 270.000 | 188.000 | 4.500 | 4.500 | 4.500
H82 | HOLE | 284.000 | 188.000 | 4.500 | 4.500 | 4.500
H83 | HOLE | 63.587 | 193.430 | 4.500 | 4.500 | 4.500
H84 | HOLE | 79.587 | 193.430 | 4.500 | 4.500 | 4.500
H85 | HOLE | 220.353 | 193.430 | 4.500 | 4.500 | 4.500
H86 | HOLE | 236.353 | 193.430 | 4.500 | 4.500 | 4.500
H87 | HOLE | 41.000 | 196.000 | 4.500 | 4.500 | 4.500
H88 | HOLE | 263.000 | 196.000 | 4.500 | 4.500 | 4.500

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

Coordinate schedule - BOTTOM_PLATE | F-101-H5
V13-REISSUE-20260929 | 2026-09-29 | mm | A3 | fitted views: use written dimensions | SHEET 24 / 202
ID | FEATURE | X from A | Y from B | DIA | WIDTH | HEIGHT
H89 | HOLE | 135.970 | 196.430 | 3.400 | 3.400 | 3.400
H90 | HOLE | 163.970 | 196.430 | 3.400 | 3.400 | 3.400
H91 | HOLE | 146.000 | 199.000 | 3.400 | 3.400 | 3.400
H92 | HOLE | 222.000 | 199.000 | 3.400 | 3.400 | 3.400
H93 | HOLE | 10.000 | 208.000 | 4.500 | 4.500 | 4.500
H94 | HOLE | 26.000 | 208.000 | 4.500 | 4.500 | 4.500
H95 | HOLE | 83.000 | 208.000 | 4.500 | 4.500 | 4.500
H96 | HOLE | 97.000 | 208.000 | 4.500 | 4.500 | 4.500
H97 | HOLE | 149.970 | 208.000 | 4.500 | 4.500 | 4.500
H98 | HOLE | 213.000 | 208.000 | 4.500 | 4.500 | 4.500
H99 | HOLE | 227.000 | 208.000 | 4.500 | 4.500 | 4.500
H100 | HOLE | 270.000 | 208.000 | 4.500 | 4.500 | 4.500
H101 | HOLE | 284.000 | 208.000 | 4.500 | 4.500 | 4.500
H102 | HOLE | 290.000 | 208.000 | 4.500 | 4.500 | 4.500
H103 | CUTOUT | 40.500 | 209.000 | - | 5.500 | 6.500
H104 | HOLE | 263.000 | 210.000 | 4.500 | 4.500 | 4.500

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

Fabrication - BATTERY_PLATE | F-102

## CUSTOM_BATTERY_PLATE

Qty1 | PVC foam / Fomex | thickness/depth 5.000 mm

SIDE EDGE PROJECTION - X / DEPTH

Assembly datum XYZ: 48.000, 47.000, 134.390

VERIFIED CAD NOMINAL: geometry measured from the final model; hardware interfaces may require ASSEMBLY ADJUST.

DXF through-cut profile supplied; units mm, arc tolerance0.01; no kerf allowance.

Fabrication - CHASSIS_PAD_0_0 | F-103
V13-REISSUE-20260929 | 2026-09-29 | mm | A3 | fitted views: use written dimensions | SHEET 26 / 202

## CUSTOM_CHASSIS_PAD_0_0

Qty1 | PVC foam / Fomex | thickness/depth 5.000 mm

20.000

20.000

Datum A: X=0 | Datum B: Y=0

H01

ID | X | Y | SIZE
H01 | 10.000 | 10.000 | DIA 4.500

SIDE EDGE PROJECTION - X / DEPTH

Depth 5.000

Assembly datum XYZ: 31.625, 52.648, 119.390 u (1.0, 0.0, 0.0); v (0.0, 1.0, 0.0)

VERIFIED CAD NOMINAL: geometry measured from the final model; hardware interfaces may require ASSEMBLY ADJUST.

3D relief / multiple depths: individual STEP and side projection control. Dashed projected edges are not through-cut instructions.

Fabrication - CHASSIS_PAD_0_1 | F-104

## CUSTOM_CHASSIS_PAD_0_1

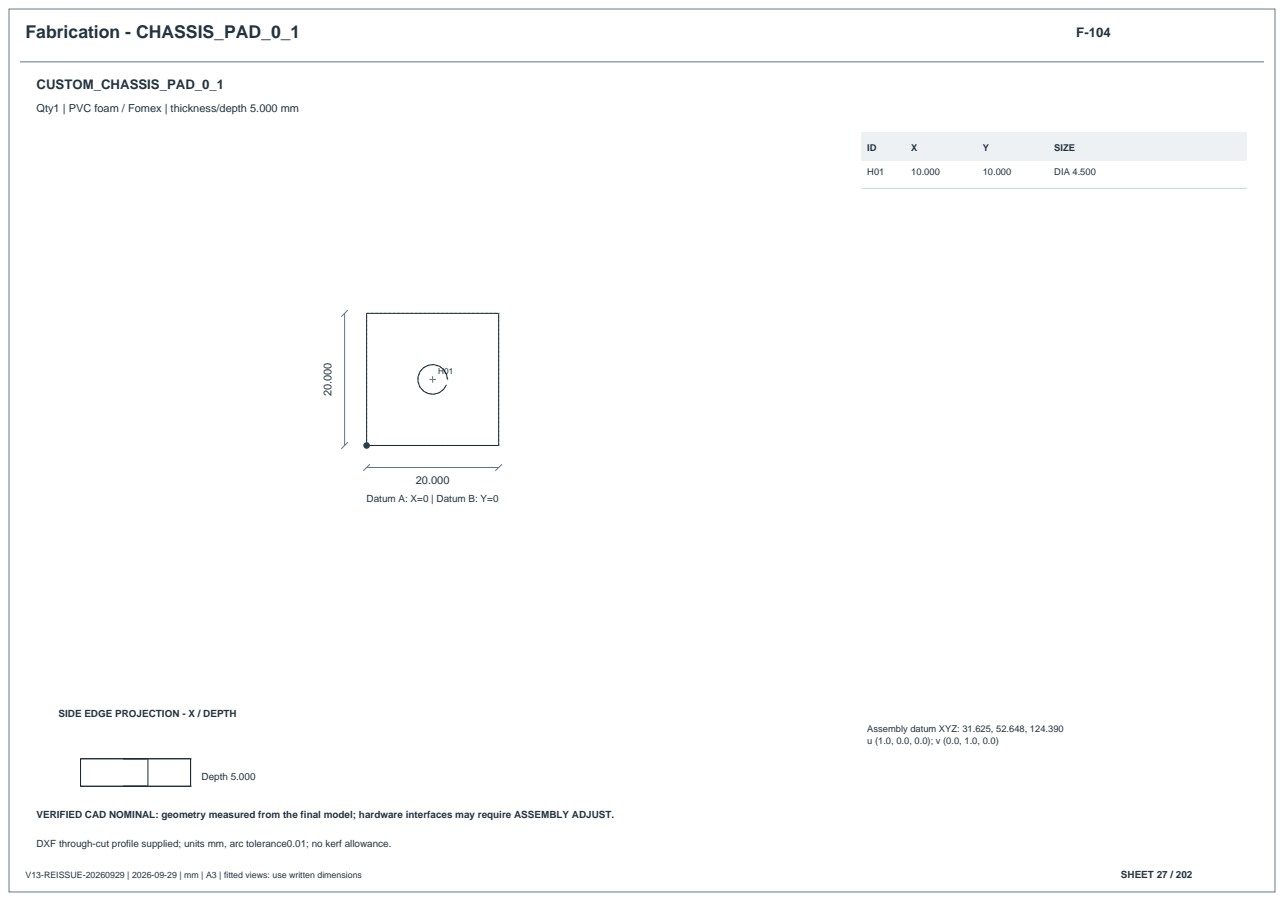
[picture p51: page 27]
V13-REISSUE-20260929 | 2026-09-29 | mm | A3 | fitted views: use written dimensions; SHEET 27 / 202; Datum A: X=0 | Datum B: Y=0; SIZE; DIA 4.500; Depth 5.000

Qty1 | PVC foam / Fomex | thickness/depth 5.000 mm

SIDE EDGE PROJECTION - X / DEPTH

Assembly datum XYZ: 31.625, 52.648, 124.390

VERIFIED CAD NOMINAL: geometry measured from the final model; hardware interfaces may require ASSEMBLY ADJUST.

DXF through-cut profile supplied; units mm, arc tolerance0.01; no kerf allowance.

Fabrication - CHASSIS_PAD_1_0 | F-105
V13-REISSUE-20260929 | 2026-09-29 | mm | A3 | fitted views: use written dimensions | SHEET 28 / 202

## CUSTOM_CHASSIS_PAD_1_0

Qty1 | PVC foam / Fomex | thickness/depth 5.000 mm

20.000

20.000

Datum A: X=0 | Datum B: Y=0

H01

ID | X | Y | SIZE
H01 | 10.000 | 10.000 | DIA 4.500

SIDE EDGE PROJECTION - X / DEPTH

Depth 5.000

Assembly datum XYZ: 31.625, 120.965, 119.390 u (1.0, 0.0, 0.0); v (0.0, 1.0, 0.0)

VERIFIED CAD NOMINAL: geometry measured from the final model; hardware interfaces may require ASSEMBLY ADJUST.

Fabrication - CHASSIS_PAD_1_1 | F-106

## CUSTOM_CHASSIS_PAD_1_1

Qty1 | PVC foam / Fomex | thickness/depth 5.000 mm

SIDE EDGE PROJECTION - X / DEPTH

Assembly datum XYZ: 31.625, 120.965, 124.390

VERIFIED CAD NOMINAL: geometry measured from the final model; hardware interfaces may require ASSEMBLY ADJUST.

DXF through-cut profile supplied; units mm, arc tolerance0.01; no kerf allowance.

Fabrication - CHASSIS_PAD_2_0 | F-107
V13-REISSUE-20260929 | 2026-09-29 | mm | A3 | fitted views: use written dimensions | SHEET 30 / 202

## CUSTOM_CHASSIS_PAD_2_0

Qty1 | PVC foam / Fomex | thickness/depth 5.000 mm

20.000

20.000

Datum A: X=0 | Datum B: Y=0

H01

ID | X | Y | SIZE
H01 | 10.000 | 10.000 | DIA 4.500

SIDE EDGE PROJECTION - X / DEPTH

Depth 5.000

Assembly datum XYZ: 218.438, 55.433, 119.390 u (1.0, 0.0, 0.0); v (0.0, 1.0, 0.0)

VERIFIED CAD NOMINAL: geometry measured from the final model; hardware interfaces may require ASSEMBLY ADJUST.

Fabrication - CHASSIS_PAD_2_1 | F-108

## CUSTOM_CHASSIS_PAD_2_1

Qty1 | PVC foam / Fomex | thickness/depth 5.000 mm

SIDE EDGE PROJECTION - X / DEPTH

Assembly datum XYZ: 218.438, 55.433, 124.390

VERIFIED CAD NOMINAL: geometry measured from the final model; hardware interfaces may require ASSEMBLY ADJUST.

DXF through-cut profile supplied; units mm, arc tolerance0.01; no kerf allowance.

Fabrication - CHASSIS_PAD_3_0 | F-109
V13-REISSUE-20260929 | 2026-09-29 | mm | A3 | fitted views: use written dimensions | SHEET 32 / 202

## CUSTOM_CHASSIS_PAD_3_0

Qty1 | PVC foam / Fomex | thickness/depth 5.000 mm

20.000

20.000

Datum A: X=0 | Datum B: Y=0

H01

ID | X | Y | SIZE
H01 | 10.000 | 10.000 | DIA 4.500

SIDE EDGE PROJECTION - X / DEPTH

Depth 5.000

Assembly datum XYZ: 218.438, 118.180, 119.390 u (1.0, 0.0, 0.0); v (0.0, 1.0, 0.0)

VERIFIED CAD NOMINAL: geometry measured from the final model; hardware interfaces may require ASSEMBLY ADJUST.

Fabrication - CHASSIS_PAD_3_1 | F-110

## CUSTOM_CHASSIS_PAD_3_1

Qty1 | PVC foam / Fomex | thickness/depth 5.000 mm

SIDE EDGE PROJECTION - X / DEPTH

Assembly datum XYZ: 218.438, 118.180, 124.390

VERIFIED CAD NOMINAL: geometry measured from the final model; hardware interfaces may require ASSEMBLY ADJUST.

DXF through-cut profile supplied; units mm, arc tolerance0.01; no kerf allowance.

Fabrication - ELECTRONICS_PLATE | F-111

## CUSTOM_ELECTRONICS_PLATE

Qty1 | PVC foam / Fomex | thickness/depth 5.000 mm

Full XY schedule follows; cross marks locate centers.

SIDE EDGE PROJECTION - X / DEPTH

Assembly datum XYZ: -10.000, -15.000, 255.000

VERIFIED CAD NOMINAL: geometry measured from the final model; hardware interfaces may require ASSEMBLY ADJUST.

DXF through-cut profile supplied; units mm, arc tolerance0.01; no kerf allowance.

Coordinate schedule - ELECTRONICS_PLATE | F-111-H1
V13-REISSUE-20260929 | 2026-09-29 | mm | A3 | fitted views: use written dimensions | SHEET 35 / 202
ID | FEATURE | X from A | Y from B | DIA | WIDTH | HEIGHT
H01 | HOLE | 41.000 | 13.000 | 4.500 | 4.500 | 4.500
H02 | HOLE | 263.000 | 13.000 | 4.500 | 4.500 | 4.500
H03 | HOLE | 10.000 | 15.000 | 4.500 | 4.500 | 4.500
H04 | HOLE | 149.970 | 15.000 | 4.500 | 4.500 | 4.500
H05 | HOLE | 290.000 | 15.000 | 4.500 | 4.500 | 4.500
H06 | CUTOUT | 127.000 | 20.387 | - | 8.800 | 14.212
H07 | HOLE | 41.000 | 27.000 | 4.500 | 4.500 | 4.500
H08 | HOLE | 263.000 | 27.000 | 4.500 | 4.500 | 4.500
H09 | HOLE | 131.000 | 43.000 | 3.400 | 3.400 | 3.400
H10 | HOLE | 234.000 | 45.700 | 3.400 | 3.400 | 3.400
H11 | HOLE | 294.000 | 45.700 | 3.400 | 3.400 | 3.400
H12 | HOLE | 147.921 | 49.921 | 3.400 | 3.400 | 3.400
H13 | HOLE | 226.661 | 49.921 | 3.400 | 3.400 | 3.400
H14 | SLOT | 20.000 | 61.000 | - | 15.000 | 50.000
H15 | CUTOUT | 80.000 | 84.500 | - | 74.000 | 53.000
H16 | SLOT | 280.000 | 91.000 | - | 15.000 | 50.000
H17 | HOLE | 147.921 | 105.801 | 3.400 | 3.400 | 3.400
H18 | HOLE | 226.661 | 105.801 | 3.400 | 3.400 | 3.400
H19 | HOLE | 237.000 | 116.000 | 3.400 | 3.400 | 3.400
H20 | HOLE | 257.000 | 116.000 | 3.400 | 3.400 | 3.400
H21 | HOLE | 261.000 | 116.000 | 3.400 | 3.400 | 3.400
H22 | HOLE | 178.000 | 117.000 | 3.400 | 3.400 | 3.400

Same datum as F-111. Dimensions are CAD nominal. Noncircular width/height are feature bounding dimensions; the STEP / supplied DXF controls the actual contour.

Coordinate schedule - ELECTRONICS_PLATE | F-111-H2
V13-REISSUE-20260929 | 2026-09-29 | mm | A3 | fitted views: use written dimensions | SHEET 36 / 202
ID | FEATURE | X from A | Y from B | DIA | WIDTH | HEIGHT
H23 | HOLE | 198.000 | 117.000 | 3.400 | 3.400 | 3.400
H24 | HOLE | 203.540 | 126.540 | 3.400 | 3.400 | 3.400
H25 | HOLE | 223.860 | 126.540 | 3.400 | 3.400 | 3.400
H26 | HOLE | 237.000 | 128.000 | 3.400 | 3.400 | 3.400
H27 | HOLE | 257.000 | 128.000 | 3.400 | 3.400 | 3.400
H28 | HOLE | 178.000 | 129.000 | 3.400 | 3.400 | 3.400
H29 | HOLE | 198.000 | 129.000 | 3.400 | 3.400 | 3.400
H30 | HOLE | 237.000 | 133.000 | 3.400 | 3.400 | 3.400
H31 | HOLE | 261.000 | 133.000 | 3.400 | 3.400 | 3.400
H32 | HOLE | 233.500 | 134.500 | 3.400 | 3.400 | 3.400
H33 | HOLE | 269.000 | 134.500 | 3.400 | 3.400 | 3.400
H34 | HOLE | 136.000 | 136.000 | 3.400 | 3.400 | 3.400
H35 | HOLE | 190.000 | 136.000 | 3.400 | 3.400 | 3.400
H36 | HOLE | 22.000 | 140.000 | 3.400 | 3.400 | 3.400
H37 | HOLE | 131.000 | 140.000 | 3.400 | 3.400 | 3.400
H38 | HOLE | 138.000 | 140.000 | 3.400 | 3.400 | 3.400
H39 | HOLE | 187.000 | 140.000 | 3.400 | 3.400 | 3.400
H40 | HOLE | 203.540 | 144.320 | 3.400 | 3.400 | 3.400
H41 | HOLE | 223.860 | 144.320 | 3.400 | 3.400 | 3.400
H42 | CUTOUT | 190.000 | 148.843 | - | 4.100 | 4.178
H43 | CUTOUT | 45.000 | 149.875 | - | 12.000 | 4.250
H44 | CUTOUT | 116.000 | 149.875 | - | 12.000 | 4.250

Same datum as F-111. Dimensions are CAD nominal. Noncircular width/height are feature bounding dimensions; the STEP / supplied DXF controls the actual contour.

Coordinate schedule - ELECTRONICS_PLATE | F-111-H3
V13-REISSUE-20260929 | 2026-09-29 | mm | A3 | fitted views: use written dimensions | SHEET 37 / 202
ID | FEATURE | X from A | Y from B | DIA | WIDTH | HEIGHT
H45 | HOLE | 30.000 | 152.000 | 3.400 | 3.400 | 3.400
H46 | HOLE | 131.000 | 152.000 | 3.400 | 3.400 | 3.400
H47 | CUTOUT | 199.083 | 153.516 | - | 4.826 | 4.924
H48 | HOLE | 233.500 | 154.500 | 3.400 | 3.400 | 3.400
H49 | HOLE | 269.000 | 154.500 | 3.400 | 3.400 | 3.400
H50 | CUTOUT | 60.000 | 159.250 | - | 11.200 | 2.800
H51 | CUTOUT | 116.000 | 159.250 | - | 11.200 | 2.800
H52 | HOLE | 201.000 | 161.000 | 3.400 | 3.400 | 3.400
H53 | HOLE | 258.000 | 161.000 | 3.400 | 3.400 | 3.400
H54 | HOLE | 30.000 | 162.000 | 3.400 | 3.400 | 3.400
H55 | HOLE | 131.000 | 162.000 | 3.400 | 3.400 | 3.400
H56 | HOLE | 138.000 | 163.000 | 3.400 | 3.400 | 3.400
H57 | HOLE | 187.000 | 163.000 | 3.400 | 3.400 | 3.400
H58 | HOLE | 136.000 | 166.000 | 3.400 | 3.400 | 3.400
H59 | HOLE | 190.000 | 166.000 | 3.400 | 3.400 | 3.400
H60 | HOLE | 234.000 | 177.700 | 3.400 | 3.400 | 3.400
H61 | HOLE | 294.000 | 177.700 | 3.400 | 3.400 | 3.400
H62 | HOLE | 133.000 | 181.000 | 3.400 | 3.400 | 3.400
H63 | HOLE | 165.000 | 181.000 | 3.400 | 3.400 | 3.400
H64 | HOLE | 201.000 | 183.000 | 3.400 | 3.400 | 3.400
H65 | HOLE | 258.000 | 183.000 | 3.400 | 3.400 | 3.400
H66 | HOLE | 194.000 | 191.000 | 3.400 | 3.400 | 3.400

Same datum as F-111. Dimensions are CAD nominal. Noncircular width/height are feature bounding dimensions; the STEP / supplied DXF controls the actual contour.

Coordinate schedule - ELECTRONICS_PLATE | F-111-H4
V13-REISSUE-20260929 | 2026-09-29 | mm | A3 | fitted views: use written dimensions | SHEET 38 / 202
ID | FEATURE | X from A | Y from B | DIA | WIDTH | HEIGHT
H67 | HOLE | 217.000 | 191.000 | 3.400 | 3.400 | 3.400
H68 | HOLE | 30.000 | 193.000 | 3.400 | 3.400 | 3.400
H69 | HOLE | 131.000 | 193.000 | 3.400 | 3.400 | 3.400
H70 | CUTOUT | 44.875 | 195.625 | - | 12.250 | 5.250
H71 | CUTOUT | 116.000 | 195.625 | - | 12.000 | 5.250
H72 | HOLE | 263.000 | 196.000 | 4.500 | 4.500 | 4.500
H73 | HOLE | 165.000 | 201.000 | 3.400 | 3.400 | 3.400
H74 | CUTOUT | 132.000 | 202.000 | - | 5.400 | 5.400
H75 | HOLE | 194.000 | 202.000 | 3.400 | 3.400 | 3.400
H76 | HOLE | 217.000 | 202.000 | 3.400 | 3.400 | 3.400
H77 | HOLE | 30.000 | 203.000 | 3.400 | 3.400 | 3.400
H78 | HOLE | 242.000 | 204.000 | 3.400 | 3.400 | 3.400
H79 | HOLE | 274.000 | 204.000 | 3.400 | 3.400 | 3.400
H80 | CUTOUT | 60.000 | 206.750 | - | 11.200 | 2.800
H81 | CUTOUT | 116.000 | 206.750 | - | 11.200 | 2.800
H82 | HOLE | 10.000 | 208.000 | 4.500 | 4.500 | 4.500
H83 | HOLE | 149.970 | 208.000 | 4.500 | 4.500 | 4.500
H84 | HOLE | 290.000 | 208.000 | 4.500 | 4.500 | 4.500
H85 | HOLE | 41.000 | 210.000 | 4.500 | 4.500 | 4.500
H86 | HOLE | 263.000 | 210.000 | 4.500 | 4.500 | 4.500
H87 | HOLE | 242.000 | 216.000 | 3.400 | 3.400 | 3.400
H88 | HOLE | 274.000 | 216.000 | 3.400 | 3.400 | 3.400

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

Fabrication - LEFT_PANEL | F-112

## CUSTOM_LEFT_PANEL

Qty1 | PVC foam / Fomex | thickness/depth 5.000 mm

Full XY schedule follows; cross marks locate centers.

SIDE EDGE PROJECTION - X / DEPTH

Assembly datum XYZ: -4.900, -10.000, 134.390

VERIFIED CAD NOMINAL: geometry measured from the final model; hardware interfaces may require ASSEMBLY ADJUST.

DXF through-cut profile supplied; units mm, arc tolerance0.01; no kerf allowance.

Coordinate schedule - LEFT_PANEL | F-112-H1
V13-REISSUE-20260929 | 2026-09-29 | mm | A3 | fitted views: use written dimensions | SHEET 40 / 202
ID | FEATURE | X from A | Y from B | DIA | WIDTH | HEIGHT
H01 | HOLE | 35.900 | 8.000 | 4.500 | 4.500 | 4.500
H02 | HOLE | 257.900 | 8.000 | 4.500 | 4.500 | 4.500
H03 | CUTOUT | 14.186 | 9.813 | - | 10.673 | 8.506
H04 | HOLE | 77.900 | 10.000 | 4.500 | 4.500 | 4.500
H05 | HOLE | 91.900 | 10.000 | 4.500 | 4.500 | 4.500
H06 | HOLE | 207.900 | 10.000 | 4.500 | 4.500 | 4.500
H07 | HOLE | 221.900 | 10.000 | 4.500 | 4.500 | 4.500
H08 | HOLE | 35.900 | 22.000 | 4.500 | 4.500 | 4.500
H09 | HOLE | 257.900 | 22.000 | 4.500 | 4.500 | 4.500
H10 | CUTOUT | 143.900 | 60.807 | - | 172.000 | 66.114
H11 | SLOT | 25.900 | 66.000 | - | 12.000 | 44.000
H12 | SLOT | 257.900 | 66.000 | - | 12.000 | 44.000
H13 | CUTOUT | 268.175 | 95.610 | - | 25.050 | 20.400
H14 | HOLE | 35.900 | 98.610 | 4.500 | 4.500 | 4.500
H15 | HOLE | 19.900 | 105.610 | 4.100 | 4.100 | 4.100
H16 | HOLE | 15.400 | 110.610 | 2.200 | 2.200 | 2.200
H17 | HOLE | 24.400 | 110.610 | 2.200 | 2.200 | 2.200
H18 | HOLE | 90.400 | 110.610 | 2.200 | 2.200 | 2.200
H19 | HOLE | 99.400 | 110.610 | 2.200 | 2.200 | 2.200
H20 | HOLE | 180.400 | 110.610 | 2.200 | 2.200 | 2.200
H21 | HOLE | 189.400 | 110.610 | 2.200 | 2.200 | 2.200
H22 | HOLE | 280.400 | 110.610 | 2.200 | 2.200 | 2.200

Same datum as F-112. Dimensions are CAD nominal. Noncircular width/height are feature bounding dimensions; the STEP / supplied DXF controls the actual contour.

Coordinate schedule - LEFT_PANEL | F-112-H2
V13-REISSUE-20260929 | 2026-09-29 | mm | A3 | fitted views: use written dimensions | SHEET 41 / 202
ID | FEATURE | X from A | Y from B | DIA | WIDTH | HEIGHT
H23 | HOLE | 289.400 | 110.610 | 2.200 | 2.200 | 2.200
H24 | CUTOUT | 34.367 | 111.535 | - | 7.566 | 6.650
H25 | CUTOUT | 122.358 | 111.866 | - | 11.079 | 6.735
H26 | HOLE | 257.900 | 112.610 | 4.500 | 4.500 | 4.500

Same datum as F-112. Dimensions are CAD nominal. Noncircular width/height are feature bounding dimensions; the STEP / supplied DXF controls the actual contour.

Fabrication - RIGHT_PANEL | F-113

## CUSTOM_RIGHT_PANEL

Qty1 | PVC foam / Fomex | thickness/depth 5.000 mm

Full XY schedule follows; cross marks locate centers.

SIDE EDGE PROJECTION - X / DEPTH

Assembly datum XYZ: -4.900, 208.000, 134.390

VERIFIED CAD NOMINAL: geometry measured from the final model; hardware interfaces may require ASSEMBLY ADJUST.

DXF through-cut profile supplied; units mm, arc tolerance0.01; no kerf allowance.

Coordinate schedule - RIGHT_PANEL | F-113-H1
V13-REISSUE-20260929 | 2026-09-29 | mm | A3 | fitted views: use written dimensions | SHEET 43 / 202
ID | FEATURE | X from A | Y from B | DIA | WIDTH | HEIGHT
H01 | HOLE | 35.900 | 8.000 | 4.500 | 4.500 | 4.500
H02 | HOLE | 257.900 | 8.000 | 4.500 | 4.500 | 4.500
H03 | HOLE | 77.900 | 10.000 | 4.500 | 4.500 | 4.500
H04 | HOLE | 91.900 | 10.000 | 4.500 | 4.500 | 4.500
H05 | HOLE | 207.900 | 10.000 | 4.500 | 4.500 | 4.500
H06 | HOLE | 221.900 | 10.000 | 4.500 | 4.500 | 4.500
H07 | HOLE | 35.900 | 22.000 | 4.500 | 4.500 | 4.500
H08 | HOLE | 257.900 | 22.000 | 4.500 | 4.500 | 4.500
H09 | CUTOUT | 143.900 | 58.875 | - | 172.000 | 62.250
H10 | SLOT | 25.900 | 66.000 | - | 12.000 | 44.000
H11 | SLOT | 257.900 | 66.000 | - | 12.000 | 44.000
H12 | CUTOUT | 12.900 | 85.610 | - | 4.500 | 8.348
H13 | HOLE | 35.900 | 98.610 | 4.500 | 4.500 | 4.500
H14 | HOLE | 257.900 | 98.610 | 4.500 | 4.500 | 4.500
H15 | CUTOUT | 12.900 | 101.770 | - | 4.500 | 5.141
H16 | CUTOUT | 24.221 | 110.312 | - | 6.243 | 6.197
H17 | HOLE | 80.400 | 110.610 | 2.200 | 2.200 | 2.200
H18 | HOLE | 89.400 | 110.610 | 2.200 | 2.200 | 2.200
H19 | HOLE | 150.400 | 110.610 | 2.200 | 2.200 | 2.200
H20 | HOLE | 159.400 | 110.610 | 2.200 | 2.200 | 2.200
H21 | HOLE | 235.400 | 110.610 | 2.200 | 2.200 | 2.200
H22 | HOLE | 244.400 | 110.610 | 2.200 | 2.200 | 2.200

Same datum as F-113. Dimensions are CAD nominal. Noncircular width/height are feature bounding dimensions; the STEP / supplied DXF controls the actual contour.

Coordinate schedule - RIGHT_PANEL | F-113-H2
V13-REISSUE-20260929 | 2026-09-29 | mm | A3 | fitted views: use written dimensions | SHEET 44 / 202
ID | FEATURE | X from A | Y from B | DIA | WIDTH | HEIGHT
H23 | CUTOUT | 16.500 | 111.460 | - | 4.400 | 3.900
H24 | HOLE | 35.900 | 112.610 | 4.500 | 4.500 | 4.500
H25 | HOLE | 257.900 | 112.610 | 4.500 | 4.500 | 4.500

Same datum as F-113. Dimensions are CAD nominal. Noncircular width/height are feature bounding dimensions; the STEP / supplied DXF controls the actual contour.

Fabrication - REAR_PANEL | F-114

## CUSTOM_REAR_PANEL

Qty1 | PVC foam / Fomex | thickness/depth 5.000 mm

SIDE EDGE PROJECTION - X / DEPTH

Assembly datum XYZ: -10.000, -10.000, 134.390

VERIFIED CAD NOMINAL: geometry measured from the final model; hardware interfaces may require ASSEMBLY ADJUST.

Fabrication - FRONT_PANEL | F-115

## CUSTOM_FRONT_PANEL

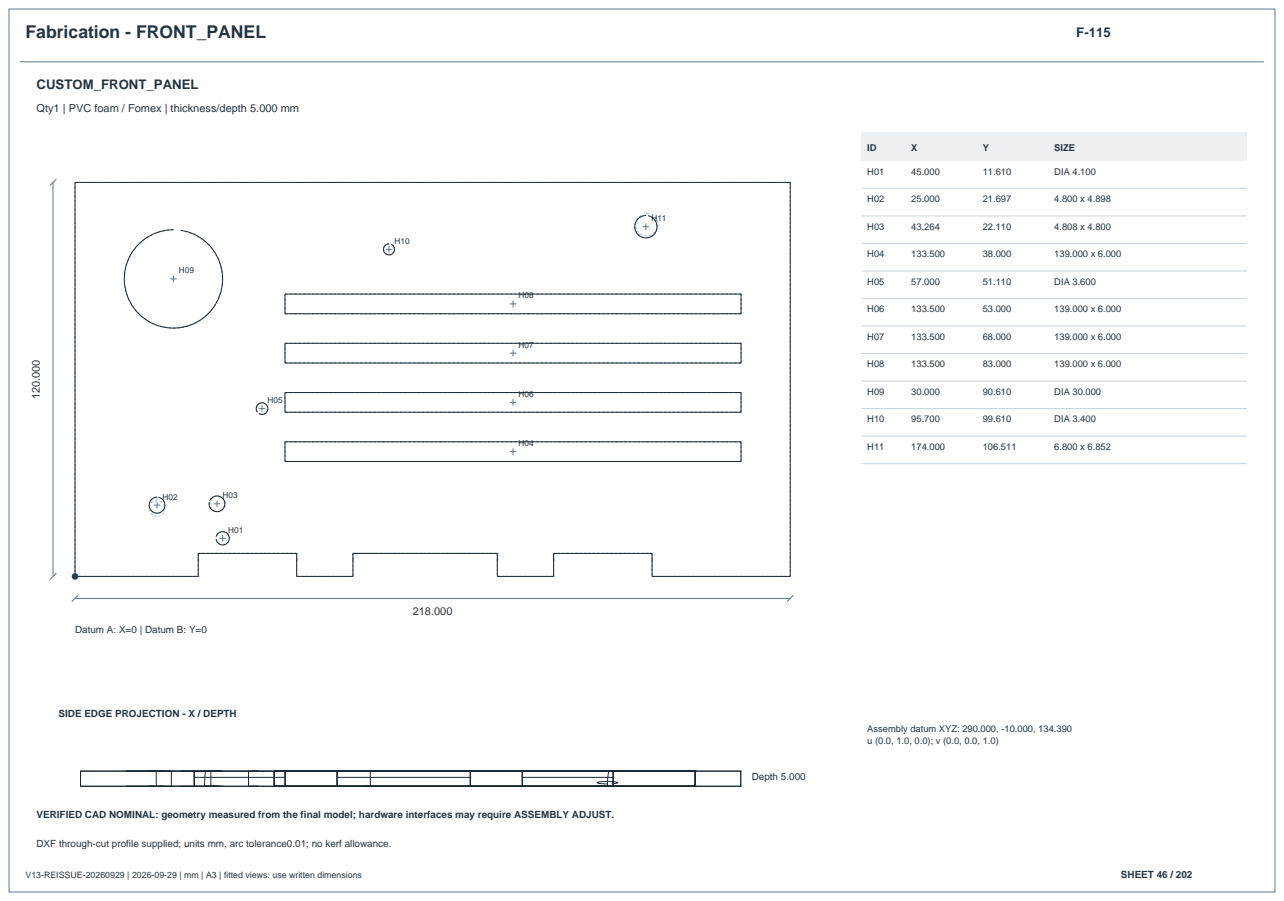
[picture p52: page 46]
V13-REISSUE-20260929 | 2026-09-29 | mm | A3 | fitted views: use written dimensions; SHEET 46 / 202; Datum A: X=0 | Datum B: Y=0; SIZE; DIA 4.100; DIA 3.600; DIA 30.000; DIA 3.400; Depth 5.000

Qty1 | PVC foam / Fomex | thickness/depth 5.000 mm

SIDE EDGE PROJECTION - X / DEPTH

Assembly datum XYZ: 290.000, -10.000, 134.390

VERIFIED CAD NOMINAL: geometry measured from the final model; hardware interfaces may require ASSEMBLY ADJUST.

DXF through-cut profile supplied; units mm, arc tolerance0.01; no kerf allowance.

Fabrication - LIDAR_BRIDGE | F-116

## CUSTOM_LIDAR_BRIDGE

Qty1 | PVC foam / Fomex | thickness/depth 5.000 mm

SIDE EDGE PROJECTION - X / DEPTH

Assembly datum XYZ: 112.970, -10.000, 354.000

VERIFIED CAD NOMINAL: geometry measured from the final model; hardware interfaces may require ASSEMBLY ADJUST.

DXF through-cut profile supplied; units mm, arc tolerance0.01; no kerf allowance.

Fabrication - LIDAR_PLATE | F-117

## CUSTOM_LIDAR_PLATE

Qty1 | PVC foam / Fomex | thickness/depth 5.000 mm

SIDE EDGE PROJECTION - X / DEPTH

Assembly datum XYZ: 93.970, 49.715, 399.000

VERIFIED CAD NOMINAL: geometry measured from the final model; hardware interfaces may require ASSEMBLY ADJUST.

DXF through-cut profile supplied; units mm, arc tolerance0.01; no kerf allowance.

Fabrication - JETSON_CRADLE | F-118

## CUSTOM_JETSON_CRADLE

Qty1 | PVC foam / Fomex | thickness/depth 5.000 mm

SIDE EDGE PROJECTION - X / DEPTH

Assembly datum XYZ: 9.000, 25.000, 266.000

VERIFIED CAD NOMINAL: geometry measured from the final model; hardware interfaces may require ASSEMBLY ADJUST.

Fabrication - BATTERY_STOP_FRONT | F-119

## CUSTOM_BATTERY_STOP_FRONT

Qty1 | PVC foam / Fomex | thickness/depth 5.000 mm

SIDE EDGE PROJECTION - X / DEPTH

Assembly datum XYZ: 213.000, 60.000, 139.390

VERIFIED CAD NOMINAL: geometry measured from the final model; hardware interfaces may require ASSEMBLY ADJUST.

DXF through-cut profile supplied; units mm, arc tolerance0.01; no kerf allowance.

Fabrication - BATTERY_STOP_REAR | F-120

## CUSTOM_BATTERY_STOP_REAR

Qty1 | PVC foam / Fomex | thickness/depth 5.000 mm

SIDE EDGE PROJECTION - X / DEPTH

Assembly datum XYZ: 53.000, 60.000, 139.390

VERIFIED CAD NOMINAL: geometry measured from the final model; hardware interfaces may require ASSEMBLY ADJUST.

DXF through-cut profile supplied; units mm, arc tolerance0.01; no kerf allowance.

Fabrication - BATTERY_STOP_LEFT | F-121

## CUSTOM_BATTERY_STOP_LEFT

Qty1 | PVC foam / Fomex | thickness/depth 5.000 mm

SIDE EDGE PROJECTION - X / DEPTH

Assembly datum XYZ: 58.000, 57.000, 139.390

VERIFIED CAD NOMINAL: geometry measured from the final model; hardware interfaces may require ASSEMBLY ADJUST.

DXF through-cut profile supplied; units mm, arc tolerance0.01; no kerf allowance.

Fabrication - BATTERY_STOP_RIGHT | F-122

## CUSTOM_BATTERY_STOP_RIGHT

Qty1 | PVC foam / Fomex | thickness/depth 5.000 mm

SIDE EDGE PROJECTION - X / DEPTH

Assembly datum XYZ: 58.000, 131.000, 139.390

VERIFIED CAD NOMINAL: geometry measured from the final model; hardware interfaces may require ASSEMBLY ADJUST.

DXF through-cut profile supplied; units mm, arc tolerance0.01; no kerf allowance.

Fabrication - HUB_TRAY | F-123

## CUSTOM_HUB_TRAY

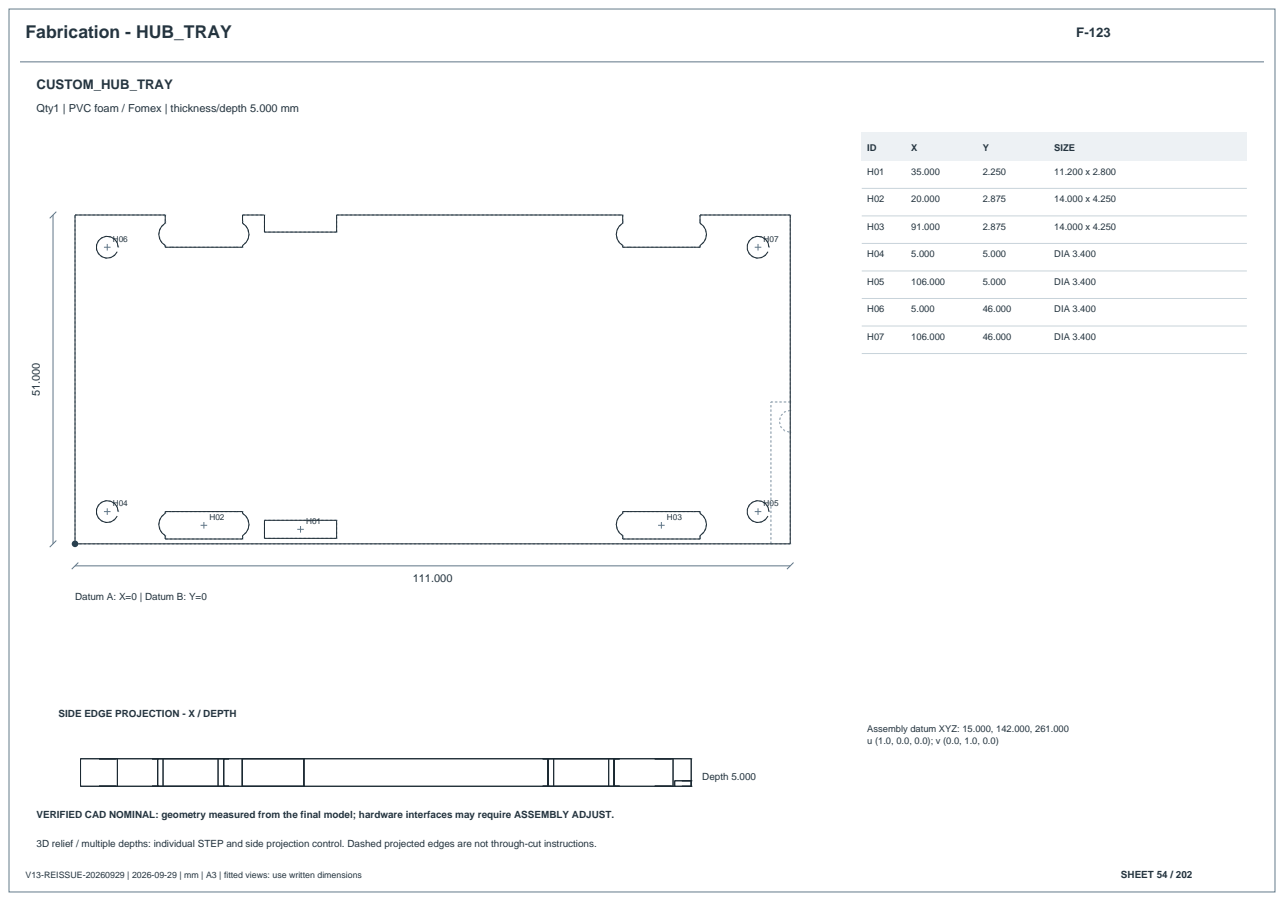
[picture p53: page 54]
V13-REISSUE-20260929 | 2026-09-29 | mm | A3 | fitted views: use written dimensions; SHEET 54 / 202; Datum A: X=0 | Datum B: Y=0; SIZE; DIA 3.400; Depth 5.000

Qty1 | PVC foam / Fomex | thickness/depth 5.000 mm

SIDE EDGE PROJECTION - X / DEPTH

Assembly datum XYZ: 15.000, 142.000, 261.000

VERIFIED CAD NOMINAL: geometry measured from the final model; hardware interfaces may require ASSEMBLY ADJUST.

Fabrication - POWER_BACKPLANE | F-124

## CUSTOM_POWER_BACKPLANE

Qty1 | PVC foam / Fomex | thickness/depth 5.000 mm

SIDE EDGE PROJECTION - X / DEPTH

Assembly datum XYZ: 15.000, 10.000, 134.390

VERIFIED CAD NOMINAL: geometry measured from the final model; hardware interfaces may require ASSEMBLY ADJUST.

Fabrication - FUSE_SHELF | F-125

## CUSTOM_FUSE_SHELF

Qty1 | PVC foam / Fomex | thickness/depth 5.000 mm

Full XY schedule follows; cross marks locate centers.

SIDE EDGE PROJECTION - X / DEPTH

Assembly datum XYZ: 47.000, 10.000, 210.000

VERIFIED CAD NOMINAL: geometry measured from the final model; hardware interfaces may require ASSEMBLY ADJUST.

Coordinate schedule - FUSE_SHELF | F-125-H1
V13-REISSUE-20260929 | 2026-09-29 | mm | A3 | fitted views: use written dimensions | SHEET 57 / 202
ID | FEATURE | X from A | Y from B | DIA | WIDTH | HEIGHT
H01 | CUTOUT | 14.500 | 4.000 | - | 3.000 | 2.000
H02 | CUTOUT | 46.500 | 4.000 | - | 3.000 | 2.000
H03 | CUTOUT | 80.500 | 4.000 | - | 3.000 | 2.000
H04 | CUTOUT | 112.500 | 4.000 | - | 3.000 | 2.000
H05 | HOLE | 8.000 | 8.000 | 3.400 | 3.400 | 3.400
H06 | HOLE | 130.000 | 8.000 | 3.400 | 3.400 | 3.400
H07 | CUTOUT | 69.395 | 14.265 | - | 5.233 | 4.807
H08 | CUTOUT | 21.498 | 20.000 | - | 14.255 | 22.000
H09 | SLOT | 48.000 | 20.000 | - | 6.000 | 22.000
H10 | SLOT | 86.000 | 20.000 | - | 4.000 | 22.000
H11 | SLOT | 114.500 | 20.000 | - | 7.000 | 22.000
H12 | CUTOUT | 94.287 | 20.748 | - | 5.139 | 5.055
H13 | CUTOUT | 14.500 | 27.000 | - | 3.000 | 2.000
H14 | CUTOUT | 80.500 | 27.000 | - | 3.000 | 2.000
H15 | CUTOUT | 33.974 | 34.000 | - | 11.176 | 4.800
H16 | HOLE | 8.000 | 35.000 | 3.400 | 3.400 | 3.400
H17 | CUTOUT | 14.877 | 35.000 | - | 6.820 | 3.600
H18 | HOLE | 130.000 | 35.000 | 3.400 | 3.400 | 3.400
H19 | CUTOUT | 41.711 | 38.000 | - | 8.966 | 3.600

Same datum as F-125. Dimensions are CAD nominal. Noncircular width/height are feature bounding dimensions; the STEP / supplied DXF controls the actual contour.

Fabrication - BOOST_BASE | F-126

## CUSTOM_BOOST_BASE

Qty1 | PVC foam / Fomex | thickness/depth 5.000 mm

SIDE EDGE PROJECTION - X / DEPTH

Assembly datum XYZ: 130.000, 150.000, 146.000

VERIFIED CAD NOMINAL: geometry measured from the final model; hardware interfaces may require ASSEMBLY ADJUST.

Fabrication - FUSEBLOCK_TRAY | F-127

## CUSTOM_FUSEBLOCK_TRAY

Qty1 | PVC foam / Fomex | thickness/depth 5.000 mm

SIDE EDGE PROJECTION - X / DEPTH

Assembly datum XYZ: 222.000, 48.000, 175.000

VERIFIED CAD NOMINAL: geometry measured from the final model; hardware interfaces may require ASSEMBLY ADJUST.

Fabrication - JETSON_BASE_RETAINER_LEFT | F-128

## CUSTOM_JETSON_BASE_RETAINER_LEFT

Qty1 | Stock material - VERIFY ON HARDWARE | thickness/depth 1.500 mm

No inner loops on the datum face.

SIDE EDGE PROJECTION - X / DEPTH

Assembly datum XYZ: 13.500, 55.000, 271.000

VERIFIED CAD NOMINAL: geometry measured from the final model; hardware interfaces may require ASSEMBLY ADJUST.

Fabrication - JETSON_BASE_RETAINER_RIGHT | F-129

## CUSTOM_JETSON_BASE_RETAINER_RIGHT

Qty1 | Stock material - VERIFY ON HARDWARE | thickness/depth 1.500 mm

No inner loops on the datum face.

SIDE EDGE PROJECTION - X / DEPTH

Assembly datum XYZ: 119.500, 55.000, 278.000

VERIFIED CAD NOMINAL: geometry measured from the final model; hardware interfaces may require ASSEMBLY ADJUST.

Fabrication - RELAY_TRAY | F-130

## CUSTOM_RELAY_TRAY

Qty1 | PVC foam / Fomex | thickness/depth 5.000 mm

SIDE EDGE PROJECTION - X / DEPTH

Assembly datum XYZ: 223.000, 9.000, 159.000

VERIFIED CAD NOMINAL: geometry measured from the final model; hardware interfaces may require ASSEMBLY ADJUST.

Fabrication - CAMERA_BASE | F-131

## CUSTOM_CAMERA_BASE

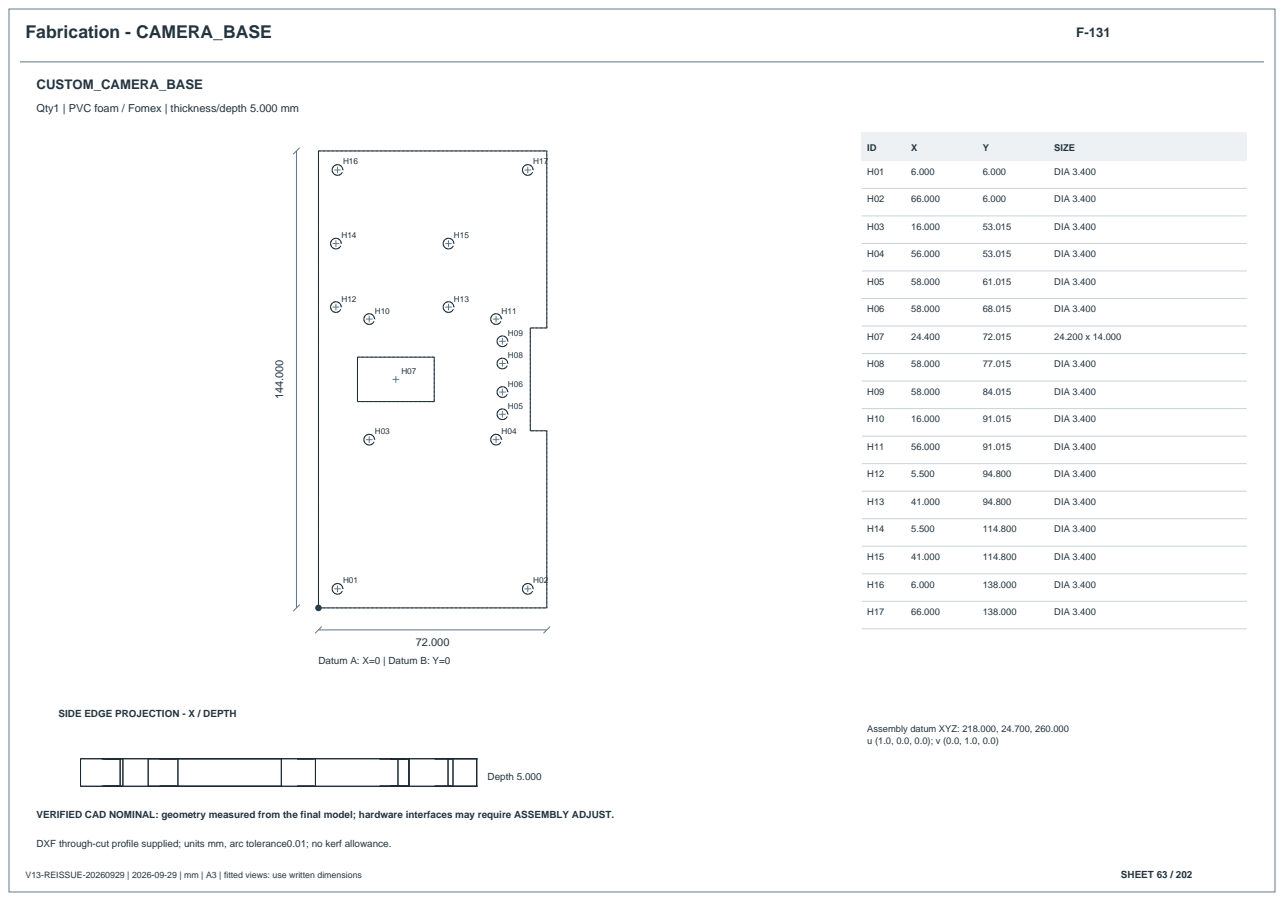
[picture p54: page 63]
V13-REISSUE-20260929 | 2026-09-29 | mm | A3 | fitted views: use written dimensions; SHEET 63 / 202; Datum A: X=0 | Datum B: Y=0; SIZE; DIA 3.400; Depth 5.000

Qty1 | PVC foam / Fomex | thickness/depth 5.000 mm

SIDE EDGE PROJECTION - X / DEPTH

Assembly datum XYZ: 218.000, 24.700, 260.000

VERIFIED CAD NOMINAL: geometry measured from the final model; hardware interfaces may require ASSEMBLY ADJUST.

DXF through-cut profile supplied; units mm, arc tolerance0.01; no kerf allowance.

Fabrication - PAN_SERVO_MOUNT | F-132

## CUSTOM_PAN_SERVO_MOUNT

Qty1 | PVC foam / Fomex | thickness/depth 5.000 mm

SIDE EDGE PROJECTION - X / DEPTH

Assembly datum XYZ: 218.500, 72.715, 277.100

VERIFIED CAD NOMINAL: geometry measured from the final model; hardware interfaces may require ASSEMBLY ADJUST.

DXF through-cut profile supplied; units mm, arc tolerance0.01; no kerf allowance.

Fabrication - PAN_YOKE | F-133

## CUSTOM_PAN_YOKE

Qty1 | PVC foam / Fomex | thickness/depth 5.000 mm

SIDE EDGE PROJECTION - X / DEPTH

Assembly datum XYZ: 211.000, 27.715, 298.000

VERIFIED CAD NOMINAL: geometry measured from the final model; hardware interfaces may require ASSEMBLY ADJUST.

Fabrication - PAN_ARM_LEFT | F-134

## CUSTOM_PAN_ARM_LEFT

Qty1 | PVC foam / Fomex | thickness/depth 5.000 mm

SIDE EDGE PROJECTION - X / DEPTH

Assembly datum XYZ: 211.000, 32.715, 303.000

VERIFIED CAD NOMINAL: geometry measured from the final model; hardware interfaces may require ASSEMBLY ADJUST.

DXF through-cut profile supplied; units mm, arc tolerance0.01; no kerf allowance.

Fabrication - CAM_L_LEFT | F-135

## APPROX_CAM_L_LEFT

Qty1 | Modified stock metal L bracket | thickness/depth 30.000 mm

SIDE EDGE PROJECTION - X / DEPTH

Assembly datum XYZ: 215.000, 62.715, 303.000

VERIFIED CAD NOMINAL: geometry measured from the final model; hardware interfaces may require ASSEMBLY ADJUST.

Fabrication - PAN_ARM_RIGHT | F-136

## CUSTOM_PAN_ARM_RIGHT

Qty1 | PVC foam / Fomex | thickness/depth 5.000 mm

SIDE EDGE PROJECTION - X / DEPTH

Assembly datum XYZ: 211.000, 160.715, 303.000

VERIFIED CAD NOMINAL: geometry measured from the final model; hardware interfaces may require ASSEMBLY ADJUST.

DXF through-cut profile supplied; units mm, arc tolerance0.01; no kerf allowance.

Fabrication - CAM_L_RIGHT | F-137

## APPROX_CAM_L_RIGHT

Qty1 | Modified stock metal L bracket | thickness/depth 30.000 mm

SIDE EDGE PROJECTION - X / DEPTH

Assembly datum XYZ: 215.000, 135.715, 333.000

VERIFIED CAD NOMINAL: geometry measured from the final model; hardware interfaces may require ASSEMBLY ADJUST.

Fabrication - TILT_SERVO_MOUNT | F-138

## CUSTOM_TILT_SERVO_MOUNT

Qty1 | PVC foam / Fomex | thickness/depth 5.000 mm

SIDE EDGE PROJECTION - X / DEPTH

Assembly datum XYZ: 218.500, 179.615, 334.000

VERIFIED CAD NOMINAL: geometry measured from the final model; hardware interfaces may require ASSEMBLY ADJUST.

DXF through-cut profile supplied; units mm, arc tolerance0.01; no kerf allowance.

Fabrication - TILT_CHEEK_LEFT | F-139

## CUSTOM_TILT_CHEEK_LEFT

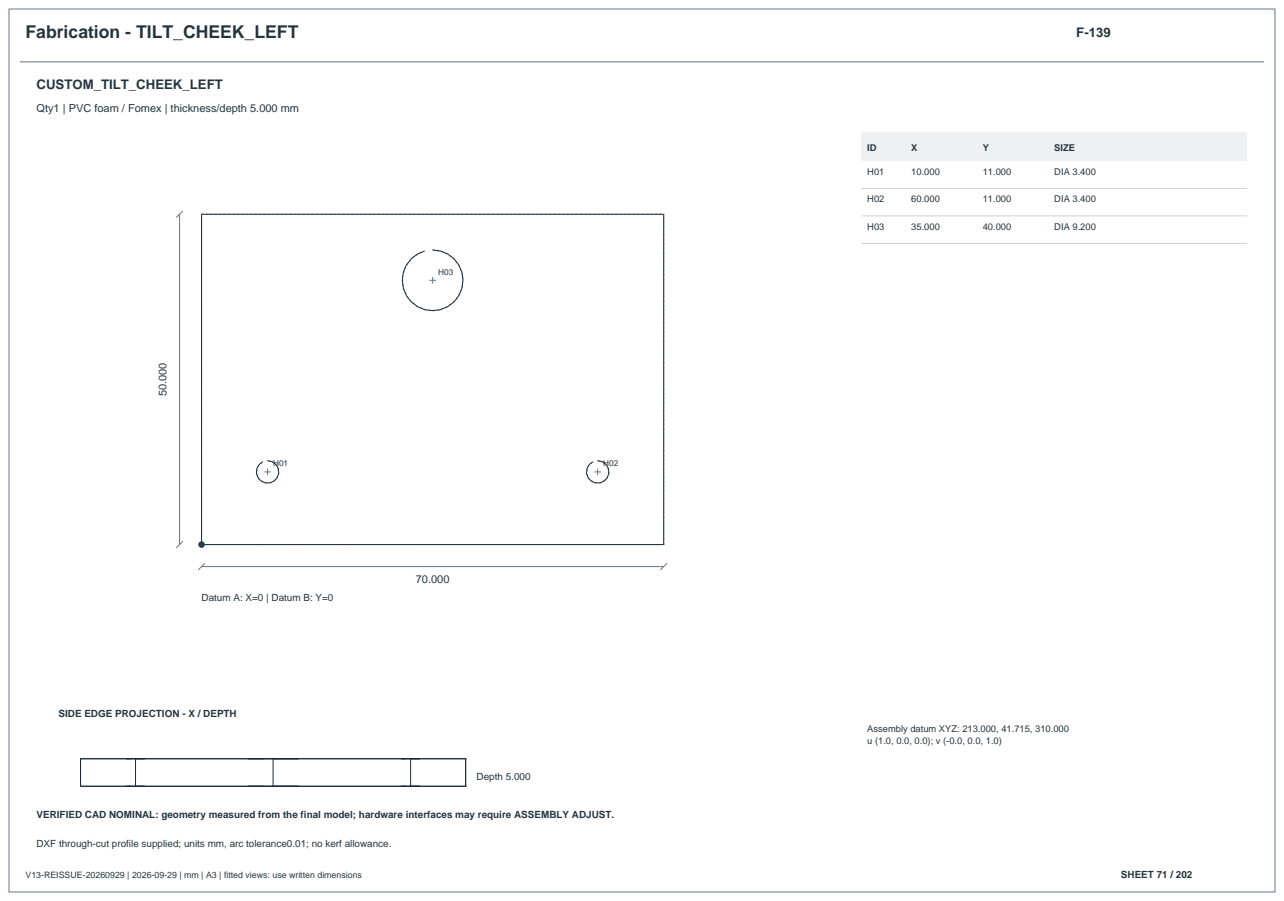
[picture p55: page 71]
V13-REISSUE-20260929 | 2026-09-29 | mm | A3 | fitted views: use written dimensions; SHEET 71 / 202; Datum A: X=0 | Datum B: Y=0; SIZE; DIA 3.400; DIA 9.200; Depth 5.000

Qty1 | PVC foam / Fomex | thickness/depth 5.000 mm

SIDE EDGE PROJECTION - X / DEPTH

Assembly datum XYZ: 213.000, 41.715, 310.000

VERIFIED CAD NOMINAL: geometry measured from the final model; hardware interfaces may require ASSEMBLY ADJUST.

DXF through-cut profile supplied; units mm, arc tolerance0.01; no kerf allowance.

Fabrication - TILT_CHEEK_RIGHT | F-140

## CUSTOM_TILT_CHEEK_RIGHT

Qty1 | PVC foam / Fomex | thickness/depth 5.000 mm

SIDE EDGE PROJECTION - X / DEPTH

Assembly datum XYZ: 213.000, 151.715, 310.000

VERIFIED CAD NOMINAL: geometry measured from the final model; hardware interfaces may require ASSEMBLY ADJUST.

DXF through-cut profile supplied; units mm, arc tolerance0.01; no kerf allowance.

Fabrication - C920_SADDLE | F-141

## CUSTOM_C920_SADDLE

Qty1 | PVC foam / Fomex | thickness/depth 5.000 mm

SIDE EDGE PROJECTION - X / DEPTH

Assembly datum XYZ: 213.000, 41.715, 310.000

VERIFIED CAD NOMINAL: geometry measured from the final model; hardware interfaces may require ASSEMBLY ADJUST.

DXF through-cut profile supplied; units mm, arc tolerance0.01; no kerf allowance.

Fabrication - TILT_CORNER_LEFT0 | F-142

## CUSTOM_TILT_CORNER_LEFT0

Qty1 | Stock material - VERIFY ON HARDWARE | thickness/depth 8.000 mm

No inner loops on the datum face.

SIDE EDGE PROJECTION - X / DEPTH

Assembly datum XYZ: 227.000, 41.715, 325.000

VERIFIED CAD NOMINAL: geometry measured from the final model; hardware interfaces may require ASSEMBLY ADJUST.

Fabrication - TILT_CORNER_LEFT1 | F-143

## CUSTOM_TILT_CORNER_LEFT1

Qty1 | Stock material - VERIFY ON HARDWARE | thickness/depth 8.000 mm

No inner loops on the datum face.

SIDE EDGE PROJECTION - X / DEPTH

Assembly datum XYZ: 277.000, 41.715, 325.000

VERIFIED CAD NOMINAL: geometry measured from the final model; hardware interfaces may require ASSEMBLY ADJUST.

Fabrication - TILT_CORNER_RIGHT0 | F-144

## CUSTOM_TILT_CORNER_RIGHT0

Qty1 | Stock material - VERIFY ON HARDWARE | thickness/depth 8.000 mm

No inner loops on the datum face.

SIDE EDGE PROJECTION - X / DEPTH

Assembly datum XYZ: 227.000, 136.715, 325.000

VERIFIED CAD NOMINAL: geometry measured from the final model; hardware interfaces may require ASSEMBLY ADJUST.

Fabrication - TILT_CORNER_RIGHT1 | F-145

## CUSTOM_TILT_CORNER_RIGHT1

Qty1 | Stock material - VERIFY ON HARDWARE | thickness/depth 8.000 mm

No inner loops on the datum face.

SIDE EDGE PROJECTION - X / DEPTH

Assembly datum XYZ: 277.000, 136.715, 325.000

VERIFIED CAD NOMINAL: geometry measured from the final model; hardware interfaces may require ASSEMBLY ADJUST.

Fabrication - TILT_BUSH_LEFT | F-146

## CUSTOM_TILT_BUSH_LEFT

Qty1 | Stock material - VERIFY ON HARDWARE | thickness/depth 9.000 mm

SIDE EDGE PROJECTION - X / DEPTH

Assembly datum XYZ: 243.500, 32.715, 354.500

VERIFIED CAD NOMINAL: geometry measured from the final model; hardware interfaces may require ASSEMBLY ADJUST.

Fabrication - THERMAL_MOUNT | F-147

## CUSTOM_THERMAL_MOUNT

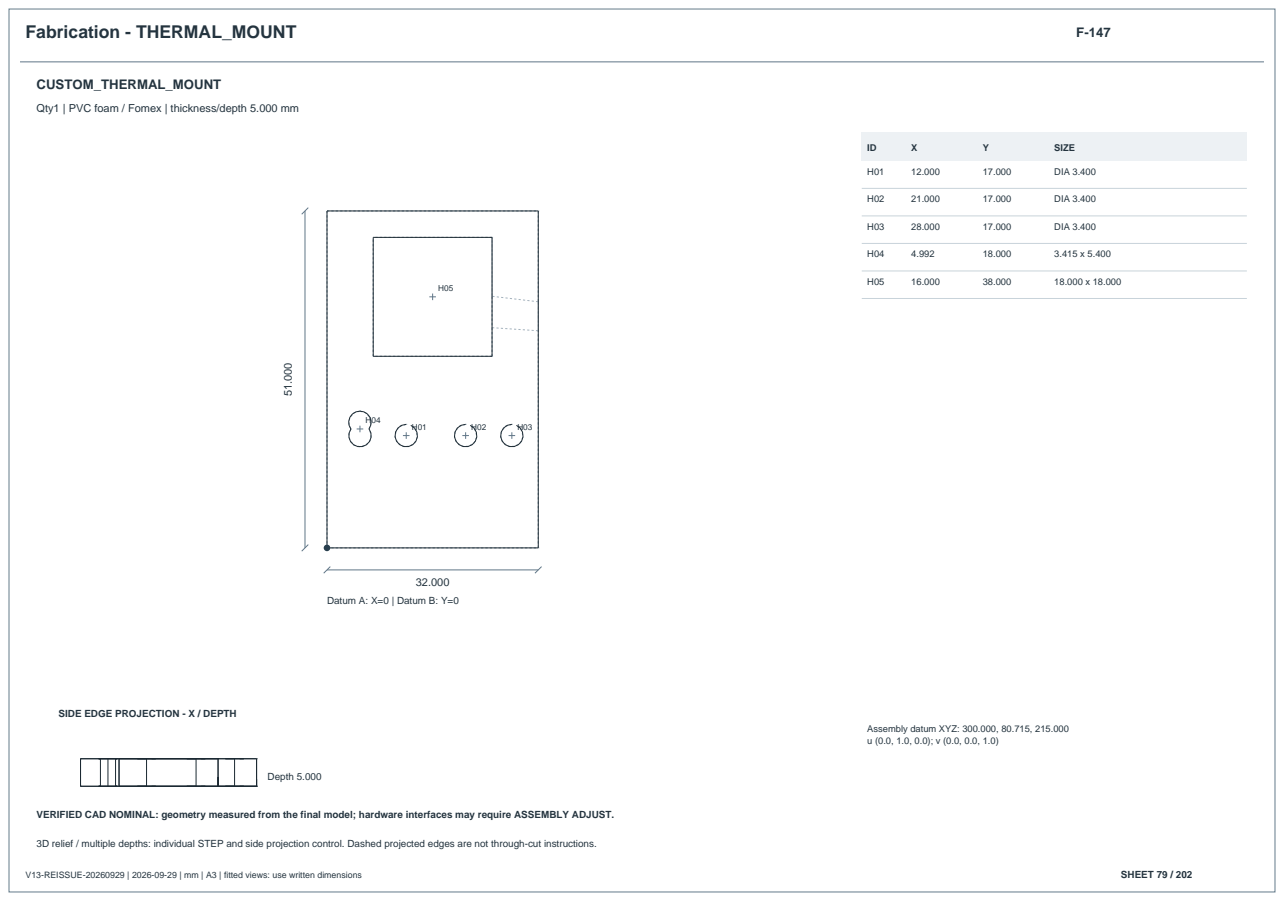
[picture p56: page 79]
V13-REISSUE-20260929 | 2026-09-29 | mm | A3 | fitted views: use written dimensions; SHEET 79 / 202; Datum A: X=0 | Datum B: Y=0; SIZE; DIA 3.400; Depth 5.000

Qty1 | PVC foam / Fomex | thickness/depth 5.000 mm

SIDE EDGE PROJECTION - X / DEPTH

Assembly datum XYZ: 300.000, 80.715, 215.000

VERIFIED CAD NOMINAL: geometry measured from the final model; hardware interfaces may require ASSEMBLY ADJUST.

Fabrication - THERMAL_ANGLE_0 | F-148

## CUSTOM_THERMAL_ANGLE_0

Qty1 | Stock material - VERIFY ON HARDWARE | thickness/depth 16.000 mm

SIDE EDGE PROJECTION - X / DEPTH

Assembly datum XYZ: 300.000, 81.715, 245.000

VERIFIED CAD NOMINAL: geometry measured from the final model; hardware interfaces may require ASSEMBLY ADJUST.

Fabrication - THERMAL_ANGLE_1 | F-149

## CUSTOM_THERMAL_ANGLE_1

Qty1 | Stock material - VERIFY ON HARDWARE | thickness/depth 16.000 mm

SIDE EDGE PROJECTION - X / DEPTH

Assembly datum XYZ: 300.000, 97.715, 245.000

VERIFIED CAD NOMINAL: geometry measured from the final model; hardware interfaces may require ASSEMBLY ADJUST.

Fabrication - THERMAL_EDGE_0 | F-150

## CUSTOM_THERMAL_EDGE_0

Qty1 | Stock material - VERIFY ON HARDWARE | thickness/depth 3.000 mm

No inner loops on the datum face.

SIDE EDGE PROJECTION - X / DEPTH

Assembly datum XYZ: 308.000, 83.715, 263.000

VERIFIED CAD NOMINAL: geometry measured from the final model; hardware interfaces may require ASSEMBLY ADJUST.

DXF through-cut profile supplied; units mm, arc tolerance0.01; no kerf allowance.

Fabrication - THERMAL_EDGE_1 | F-151

## CUSTOM_THERMAL_EDGE_1

Qty1 | Stock material - VERIFY ON HARDWARE | thickness/depth 3.000 mm

No inner loops on the datum face.

SIDE EDGE PROJECTION - X / DEPTH

Assembly datum XYZ: 308.000, 105.715, 263.000

VERIFIED CAD NOMINAL: geometry measured from the final model; hardware interfaces may require ASSEMBLY ADJUST.

DXF through-cut profile supplied; units mm, arc tolerance0.01; no kerf allowance.

Fabrication - FRONT_BUMPER | F-152

## CUSTOM_FRONT_BUMPER

Qty1 | PVC foam / Fomex | thickness/depth 5.000 mm

SIDE EDGE PROJECTION - X / DEPTH

Assembly datum XYZ: 312.939, -25.000, 45.000

VERIFIED CAD NOMINAL: geometry measured from the final model; hardware interfaces may require ASSEMBLY ADJUST.

DXF through-cut profile supplied; units mm, arc tolerance0.01; no kerf allowance.

Fabrication - FRONT_STRIKER | F-153

## CUSTOM_FRONT_STRIKER

Qty1 | Stock material - VERIFY ON HARDWARE | thickness/depth 5.000 mm

No inner loops on the datum face.

SIDE EDGE PROJECTION - X / DEPTH

Assembly datum XYZ: 307.939, 87.715, 80.000

VERIFIED CAD NOMINAL: geometry measured from the final model; hardware interfaces may require ASSEMBLY ADJUST.

Fabrication - FRONT_GUIDE_FOOT_0 | F-154

## CUSTOM_FRONT_GUIDE_FOOT_0

Qty1 | PVC foam / Fomex | thickness/depth 5.000 mm

SIDE EDGE PROJECTION - X / DEPTH

Assembly datum XYZ: 254.939, 57.555, 139.390

VERIFIED CAD NOMINAL: geometry measured from the final model; hardware interfaces may require ASSEMBLY ADJUST.

DXF through-cut profile supplied; units mm, arc tolerance0.01; no kerf allowance.

Fabrication - FRONT_GUIDE_HANGER_0 | F-155

## CUSTOM_FRONT_GUIDE_HANGER_0

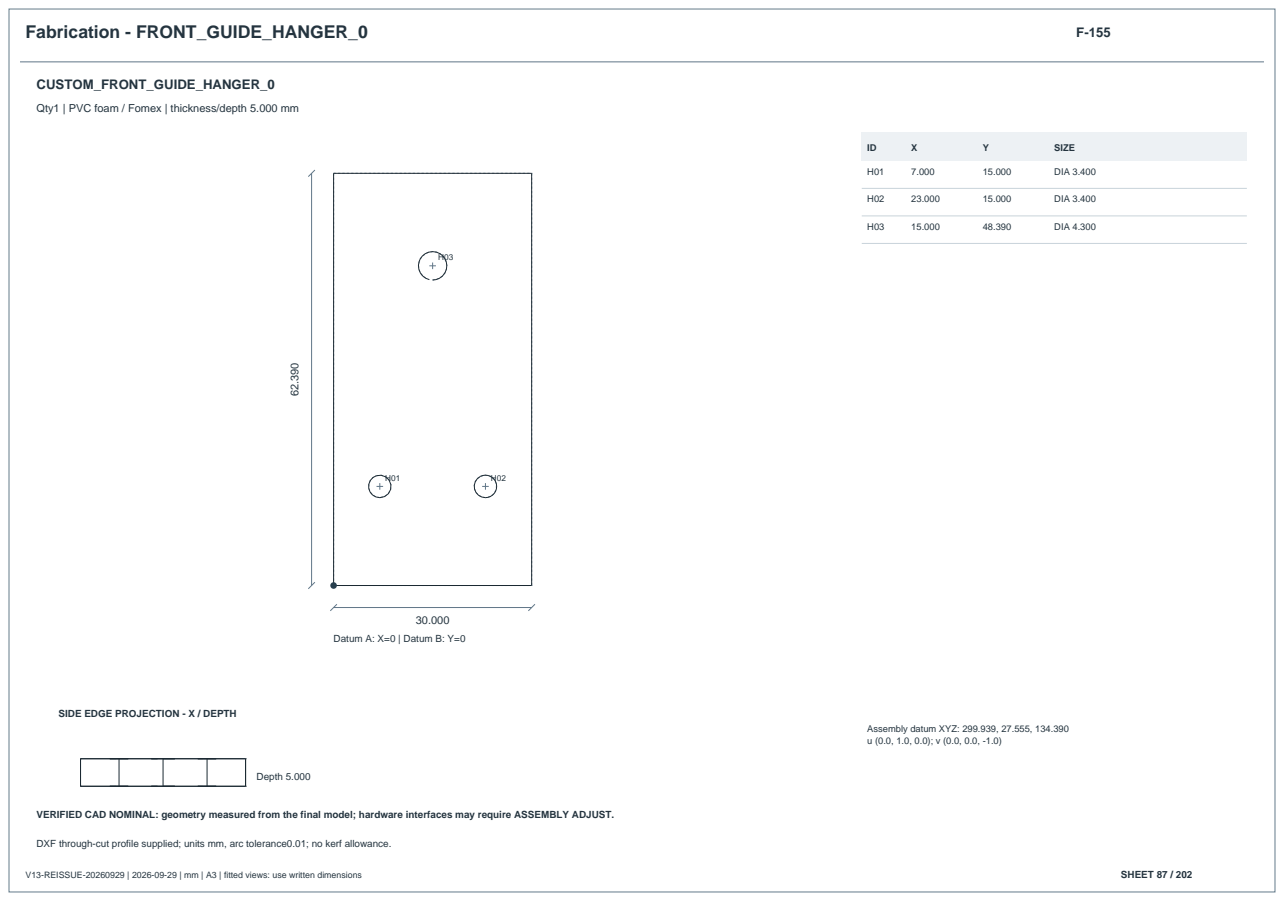
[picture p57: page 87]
V13-REISSUE-20260929 | 2026-09-29 | mm | A3 | fitted views: use written dimensions; SHEET 87 / 202; Datum A: X=0 | Datum B: Y=0; SIZE; DIA 3.400; DIA 4.300; Depth 5.000

Qty1 | PVC foam / Fomex | thickness/depth 5.000 mm

SIDE EDGE PROJECTION - X / DEPTH

Assembly datum XYZ: 299.939, 27.555, 134.390

VERIFIED CAD NOMINAL: geometry measured from the final model; hardware interfaces may require ASSEMBLY ADJUST.

DXF through-cut profile supplied; units mm, arc tolerance0.01; no kerf allowance.

Fabrication - FRONT_GUIDE_ANGLE_0 | F-156

## CUSTOM_FRONT_GUIDE_ANGLE_0

Qty1 | Stock material - VERIFY ON HARDWARE | thickness/depth 30.000 mm

SIDE EDGE PROJECTION - X / DEPTH

Assembly datum XYZ: 299.939, 27.555, 141.390

VERIFIED CAD NOMINAL: geometry measured from the final model; hardware interfaces may require ASSEMBLY ADJUST.

Fabrication - FRONT_GUIDE_BUSH_0 | F-157

## CUSTOM_FRONT_GUIDE_BUSH_0

Qty1 | Stock material - VERIFY ON HARDWARE | thickness/depth 10.000 mm

SIDE EDGE PROJECTION - X / DEPTH

Assembly datum XYZ: 307.939, 39.055, 82.500

VERIFIED CAD NOMINAL: geometry measured from the final model; hardware interfaces may require ASSEMBLY ADJUST.

Fabrication - FRONT_STOPPER_0 | F-158

## CUSTOM_FRONT_STOPPER_0

Qty1 | Stock material - VERIFY ON HARDWARE | thickness/depth 9.000 mm

SIDE EDGE PROJECTION - X / DEPTH

Assembly datum XYZ: 299.939, 36.555, 80.000

VERIFIED CAD NOMINAL: geometry measured from the final model; hardware interfaces may require ASSEMBLY ADJUST.

Fabrication - FRONT_GUIDE_FOOT_1 | F-159

## CUSTOM_FRONT_GUIDE_FOOT_1

Qty1 | PVC foam / Fomex | thickness/depth 5.000 mm

SIDE EDGE PROJECTION - X / DEPTH

Assembly datum XYZ: 254.939, 135.875, 134.390

VERIFIED CAD NOMINAL: geometry measured from the final model; hardware interfaces may require ASSEMBLY ADJUST.

DXF through-cut profile supplied; units mm, arc tolerance0.01; no kerf allowance.

Fabrication - FRONT_GUIDE_HANGER_1 | F-160

## CUSTOM_FRONT_GUIDE_HANGER_1

Qty1 | PVC foam / Fomex | thickness/depth 5.000 mm

SIDE EDGE PROJECTION - X / DEPTH

Assembly datum XYZ: 299.939, 135.875, 134.390

VERIFIED CAD NOMINAL: geometry measured from the final model; hardware interfaces may require ASSEMBLY ADJUST.

DXF through-cut profile supplied; units mm, arc tolerance0.01; no kerf allowance.

Fabrication - FRONT_GUIDE_ANGLE_1 | F-161

## CUSTOM_FRONT_GUIDE_ANGLE_1

Qty1 | Stock material - VERIFY ON HARDWARE | thickness/depth 30.000 mm

SIDE EDGE PROJECTION - X / DEPTH

Assembly datum XYZ: 299.939, 135.875, 141.390

VERIFIED CAD NOMINAL: geometry measured from the final model; hardware interfaces may require ASSEMBLY ADJUST.

Fabrication - FRONT_GUIDE_BUSH_1 | F-162

## CUSTOM_FRONT_GUIDE_BUSH_1

Qty1 | Stock material - VERIFY ON HARDWARE | thickness/depth 10.000 mm

SIDE EDGE PROJECTION - X / DEPTH

Assembly datum XYZ: 307.939, 147.375, 82.500

VERIFIED CAD NOMINAL: geometry measured from the final model; hardware interfaces may require ASSEMBLY ADJUST.

Fabrication - FRONT_STOPPER_1 | F-163

## CUSTOM_FRONT_STOPPER_1

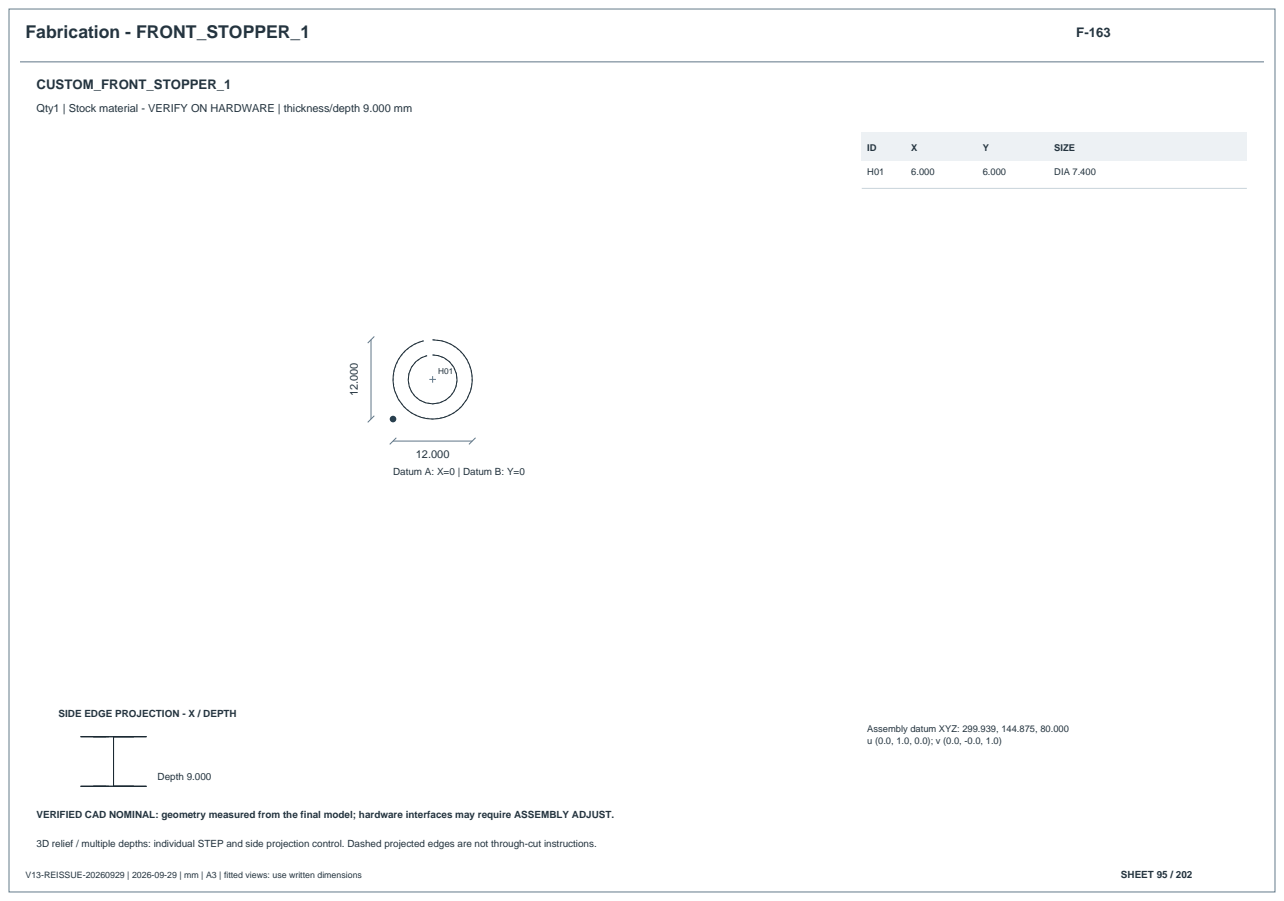
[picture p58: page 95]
V13-REISSUE-20260929 | 2026-09-29 | mm | A3 | fitted views: use written dimensions; SHEET 95 / 202; Datum A: X=0 | Datum B: Y=0; SIZE; DIA 7.400; Depth 9.000

Qty1 | Stock material - VERIFY ON HARDWARE | thickness/depth 9.000 mm

SIDE EDGE PROJECTION - X / DEPTH

Assembly datum XYZ: 299.939, 144.875, 80.000

VERIFIED CAD NOMINAL: geometry measured from the final model; hardware interfaces may require ASSEMBLY ADJUST.

Fabrication - FRONT_SWITCH_BRACKET | F-164

## CUSTOM_FRONT_SWITCH_BRACKET

Qty1 | Stock material - VERIFY ON HARDWARE | thickness/depth 5.000 mm

SIDE EDGE PROJECTION - X / DEPTH

Assembly datum XYZ: 299.939, 74.715, 134.390

VERIFIED CAD NOMINAL: geometry measured from the final model; hardware interfaces may require ASSEMBLY ADJUST.

Fabrication - FRONT_SWITCH_FOOT | F-165

## CUSTOM_FRONT_SWITCH_FOOT

Qty1 | Stock material - VERIFY ON HARDWARE | thickness/depth 5.000 mm

SIDE EDGE PROJECTION - X / DEPTH

Assembly datum XYZ: 257.939, 118.715, 139.390

VERIFIED CAD NOMINAL: geometry measured from the final model; hardware interfaces may require ASSEMBLY ADJUST.

Fabrication - FRONT_SWITCH_ANGLE | F-166

## CUSTOM_FRONT_SWITCH_ANGLE

Qty1 | Stock material - VERIFY ON HARDWARE | thickness/depth 24.000 mm

No inner loops on the datum face.

SIDE EDGE PROJECTION - X / DEPTH

Assembly datum XYZ: 271.939, 74.715, 117.390

VERIFIED CAD NOMINAL: geometry measured from the final model; hardware interfaces may require ASSEMBLY ADJUST.

Fabrication - FRONT_CORNER_NOSE_-1 | F-167

## CUSTOM_FRONT_CORNER_NOSE_-1

Qty1 | Stock material - VERIFY ON HARDWARE | thickness/depth 4.206 mm

No inner loops on the datum face.

SIDE EDGE PROJECTION - X / DEPTH

Assembly datum XYZ: 304.232, -36.545, 55.000

VERIFIED CAD NOMINAL: geometry measured from the final model; hardware interfaces may require ASSEMBLY ADJUST.

Fabrication - FRONT_CORNER_NOSE_1 | F-168

## CUSTOM_FRONT_CORNER_NOSE_1

Qty1 | Stock material - VERIFY ON HARDWARE | thickness/depth 4.206 mm

No inner loops on the datum face.

SIDE EDGE PROJECTION - X / DEPTH

Assembly datum XYZ: 304.232, 229.975, 85.000

VERIFIED CAD NOMINAL: geometry measured from the final model; hardware interfaces may require ASSEMBLY ADJUST.

Fabrication - REAR_BUMPER | F-169

## CUSTOM_REAR_BUMPER

Qty1 | PVC foam / Fomex | thickness/depth 5.000 mm

SIDE EDGE PROJECTION - X / DEPTH

Assembly datum XYZ: -33.000, 218.430, 45.000

VERIFIED CAD NOMINAL: geometry measured from the final model; hardware interfaces may require ASSEMBLY ADJUST.

DXF through-cut profile supplied; units mm, arc tolerance0.01; no kerf allowance.

Fabrication - REAR_STRIKER | F-170

## CUSTOM_REAR_STRIKER

Qty1 | Stock material - VERIFY ON HARDWARE | thickness/depth 5.000 mm

No inner loops on the datum face.

SIDE EDGE PROJECTION - X / DEPTH

Assembly datum XYZ: -28.000, 87.715, 89.000

VERIFIED CAD NOMINAL: geometry measured from the final model; hardware interfaces may require ASSEMBLY ADJUST.

Fabrication - REAR_GUIDE_FOOT_0 | F-171

## CUSTOM_REAR_GUIDE_FOOT_0

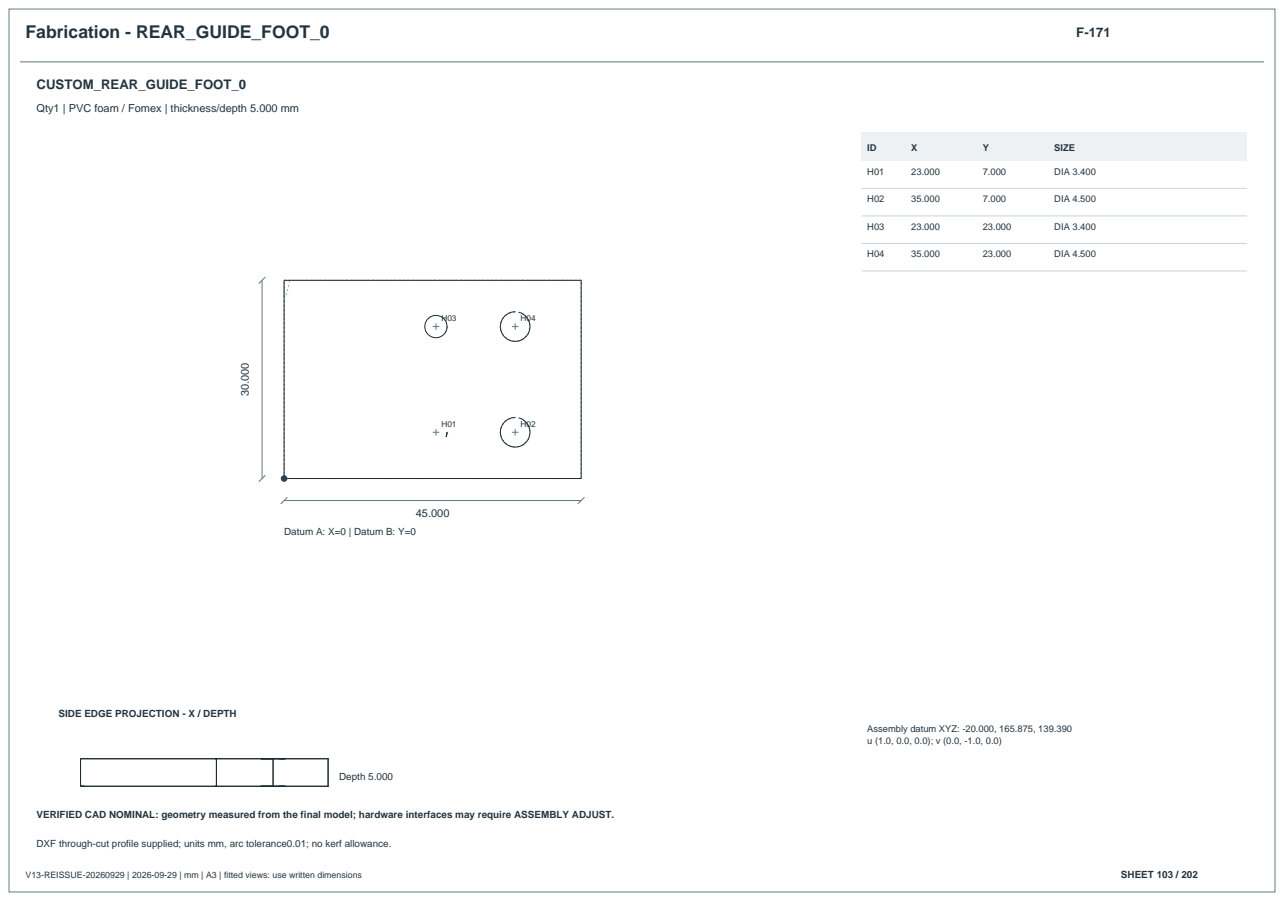
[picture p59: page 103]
V13-REISSUE-20260929 | 2026-09-29 | mm | A3 | fitted views: use written dimensions; SHEET 103 / 202; Datum A: X=0 | Datum B: Y=0; SIZE; DIA 3.400; DIA 4.500; Depth 5.000

Qty1 | PVC foam / Fomex | thickness/depth 5.000 mm

SIDE EDGE PROJECTION - X / DEPTH

Assembly datum XYZ: -20.000, 165.875, 139.390

VERIFIED CAD NOMINAL: geometry measured from the final model; hardware interfaces may require ASSEMBLY ADJUST.

DXF through-cut profile supplied; units mm, arc tolerance0.01; no kerf allowance.

Fabrication - REAR_GUIDE_HANGER_0 | F-172

## CUSTOM_REAR_GUIDE_HANGER_0

Qty1 | PVC foam / Fomex | thickness/depth 5.000 mm

SIDE EDGE PROJECTION - X / DEPTH

Assembly datum XYZ: -20.000, 135.875, 72.000

VERIFIED CAD NOMINAL: geometry measured from the final model; hardware interfaces may require ASSEMBLY ADJUST.

DXF through-cut profile supplied; units mm, arc tolerance0.01; no kerf allowance.

Fabrication - REAR_GUIDE_ANGLE_0 | F-173

## CUSTOM_REAR_GUIDE_ANGLE_0

Qty1 | Stock material - VERIFY ON HARDWARE | thickness/depth 30.000 mm

SIDE EDGE PROJECTION - X / DEPTH

Assembly datum XYZ: -20.000, 135.875, 111.390

VERIFIED CAD NOMINAL: geometry measured from the final model; hardware interfaces may require ASSEMBLY ADJUST.

Fabrication - REAR_GUIDE_BUSH_0 | F-174

## CUSTOM_REAR_GUIDE_BUSH_0

Qty1 | Stock material - VERIFY ON HARDWARE | thickness/depth 10.000 mm

SIDE EDGE PROJECTION - X / DEPTH

Assembly datum XYZ: -28.000, 147.375, 89.500

VERIFIED CAD NOMINAL: geometry measured from the final model; hardware interfaces may require ASSEMBLY ADJUST.

Fabrication - REAR_STOPPER_0 | F-175

## CUSTOM_REAR_STOPPER_0

Qty1 | Stock material - VERIFY ON HARDWARE | thickness/depth 9.000 mm

SIDE EDGE PROJECTION - X / DEPTH

Assembly datum XYZ: -20.000, 144.875, 92.000

VERIFIED CAD NOMINAL: geometry measured from the final model; hardware interfaces may require ASSEMBLY ADJUST.

Fabrication - REAR_GUIDE_FOOT_1 | F-176

## CUSTOM_REAR_GUIDE_FOOT_1

Qty1 | Stock material - VERIFY ON HARDWARE | thickness/depth 5.000 mm

SIDE EDGE PROJECTION - X / DEPTH

Assembly datum XYZ: -20.000, 27.555, 134.390

VERIFIED CAD NOMINAL: geometry measured from the final model; hardware interfaces may require ASSEMBLY ADJUST.

Fabrication - REAR_GUIDE_HANGER_1 | F-177

## CUSTOM_REAR_GUIDE_HANGER_1

Qty1 | PVC foam / Fomex | thickness/depth 5.000 mm

SIDE EDGE PROJECTION - X / DEPTH

Assembly datum XYZ: -15.000, 27.555, 134.390

VERIFIED CAD NOMINAL: geometry measured from the final model; hardware interfaces may require ASSEMBLY ADJUST.

DXF through-cut profile supplied; units mm, arc tolerance0.01; no kerf allowance.

Fabrication - REAR_GUIDE_ANGLE_1 | F-178

## CUSTOM_REAR_GUIDE_ANGLE_1

Qty1 | Stock material - VERIFY ON HARDWARE | thickness/depth 30.000 mm

SIDE EDGE PROJECTION - X / DEPTH

Assembly datum XYZ: -20.000, 27.555, 111.390

VERIFIED CAD NOMINAL: geometry measured from the final model; hardware interfaces may require ASSEMBLY ADJUST.

Fabrication - REAR_GUIDE_BUSH_1 | F-179

## CUSTOM_REAR_GUIDE_BUSH_1

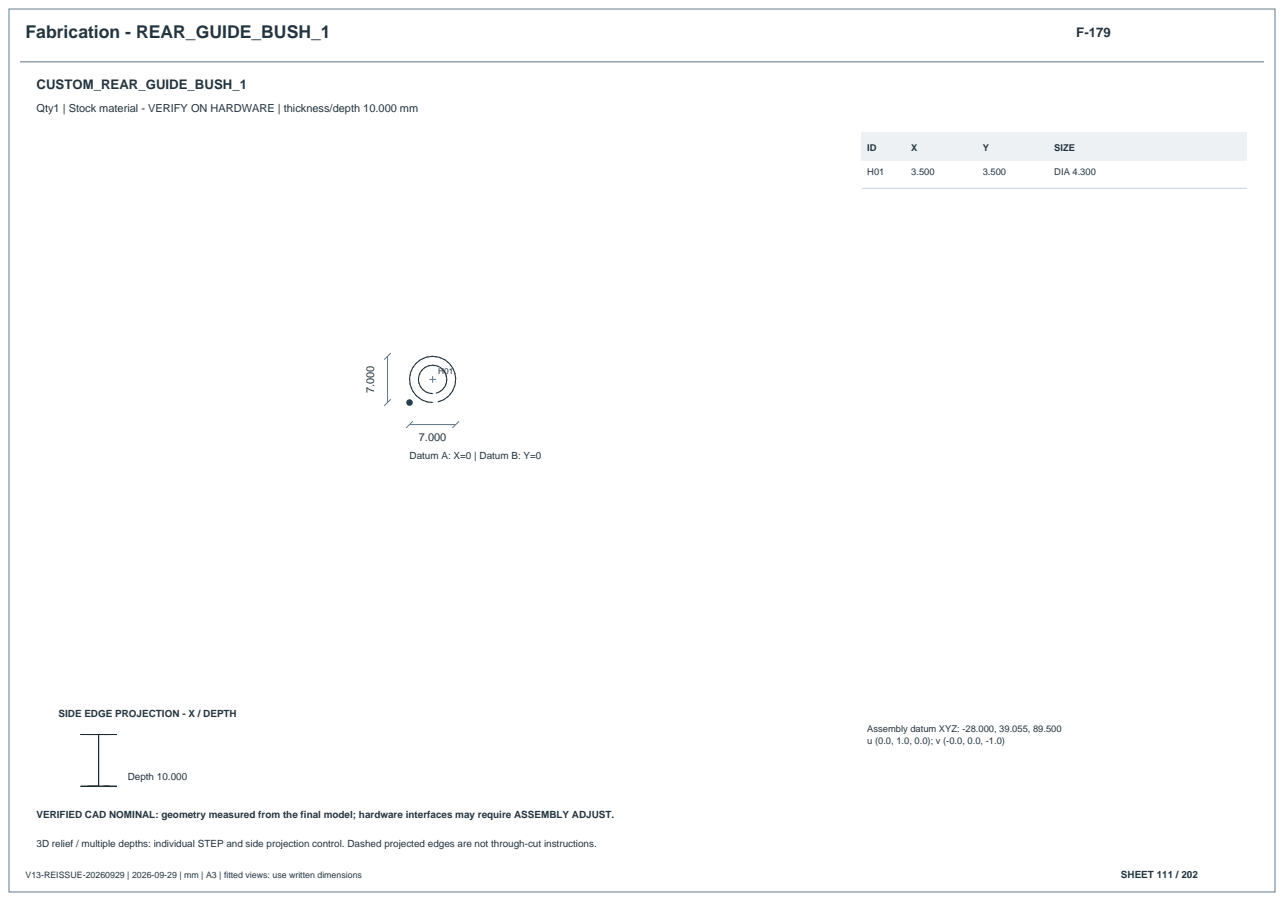
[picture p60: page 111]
V13-REISSUE-20260929 | 2026-09-29 | mm | A3 | fitted views: use written dimensions; SHEET 111 / 202; Datum A: X=0 | Datum B: Y=0; SIZE; DIA 4.300; Depth 10.000

Qty1 | Stock material - VERIFY ON HARDWARE | thickness/depth 10.000 mm

SIDE EDGE PROJECTION - X / DEPTH

Assembly datum XYZ: -28.000, 39.055, 89.500

VERIFIED CAD NOMINAL: geometry measured from the final model; hardware interfaces may require ASSEMBLY ADJUST.

Fabrication - REAR_STOPPER_1 | F-180

## CUSTOM_REAR_STOPPER_1

Qty1 | Stock material - VERIFY ON HARDWARE | thickness/depth 9.000 mm

SIDE EDGE PROJECTION - X / DEPTH

Assembly datum XYZ: -20.000, 36.555, 92.000

VERIFIED CAD NOMINAL: geometry measured from the final model; hardware interfaces may require ASSEMBLY ADJUST.

Fabrication - REAR_SWITCH_BRACKET | F-181

## CUSTOM_REAR_SWITCH_BRACKET

Qty1 | Stock material - VERIFY ON HARDWARE | thickness/depth 5.000 mm

SIDE EDGE PROJECTION - X / DEPTH

Assembly datum XYZ: -20.000, 74.715, 63.000

VERIFIED CAD NOMINAL: geometry measured from the final model; hardware interfaces may require ASSEMBLY ADJUST.

Fabrication - REAR_SWITCH_FOOT | F-182

## CUSTOM_REAR_SWITCH_FOOT

Qty1 | Stock material - VERIFY ON HARDWARE | thickness/depth 5.000 mm

SIDE EDGE PROJECTION - X / DEPTH

Assembly datum XYZ: -20.000, 118.715, 139.390

VERIFIED CAD NOMINAL: geometry measured from the final model; hardware interfaces may require ASSEMBLY ADJUST.

Fabrication - REAR_SWITCH_ANGLE | F-183

## CUSTOM_REAR_SWITCH_ANGLE

Qty1 | Stock material - VERIFY ON HARDWARE | thickness/depth 24.000 mm

No inner loops on the datum face.

SIDE EDGE PROJECTION - X / DEPTH

Assembly datum XYZ: -20.000, 118.715, 141.390

VERIFIED CAD NOMINAL: geometry measured from the final model; hardware interfaces may require ASSEMBLY ADJUST.

Fabrication - REAR_CORNER_NOSE_-1 | F-184

## CUSTOM_REAR_CORNER_NOSE_-1

Qty1 | Stock material - VERIFY ON HARDWARE | thickness/depth 4.206 mm

No inner loops on the datum face.

SIDE EDGE PROJECTION - X / DEPTH

Assembly datum XYZ: -34.462, 214.156, 85.000

VERIFIED CAD NOMINAL: geometry measured from the final model; hardware interfaces may require ASSEMBLY ADJUST.

Fabrication - REAR_CORNER_NOSE_1 | F-185

## CUSTOM_REAR_CORNER_NOSE_1

Qty1 | Stock material - VERIFY ON HARDWARE | thickness/depth 4.206 mm

No inner loops on the datum face.

SIDE EDGE PROJECTION - X / DEPTH

Assembly datum XYZ: -34.462, -20.726, 55.000

VERIFIED CAD NOMINAL: geometry measured from the final model; hardware interfaces may require ASSEMBLY ADJUST.

Fabrication - LEFT_BUMPER | F-186

## CUSTOM_LEFT_BUMPER

Qty1 | PVC foam / Fomex | thickness/depth 5.000 mm

SIDE EDGE PROJECTION - X / DEPTH

Assembly datum XYZ: -25.000, -33.000, 45.000

VERIFIED CAD NOMINAL: geometry measured from the final model; hardware interfaces may require ASSEMBLY ADJUST.

DXF through-cut profile supplied; units mm, arc tolerance0.01; no kerf allowance.

Fabrication - LEFT_STRIKER | F-187

## CUSTOM_LEFT_STRIKER

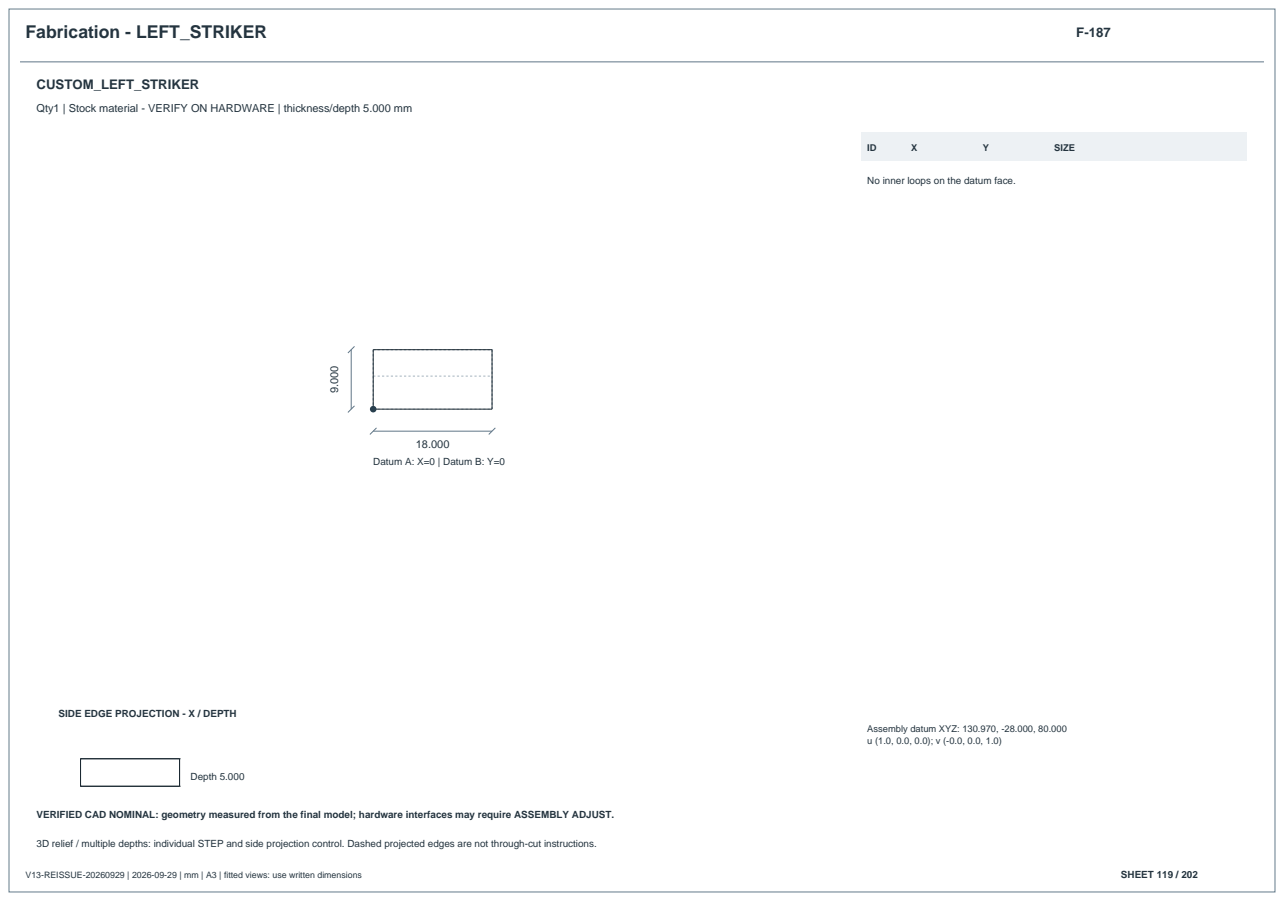
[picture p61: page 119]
V13-REISSUE-20260929 | 2026-09-29 | mm | A3 | fitted views: use written dimensions; SHEET 119 / 202; Datum A: X=0 | Datum B: Y=0; SIZE; Depth 5.000

Qty1 | Stock material - VERIFY ON HARDWARE | thickness/depth 5.000 mm

No inner loops on the datum face.

SIDE EDGE PROJECTION - X / DEPTH

Assembly datum XYZ: 130.970, -28.000, 80.000

VERIFIED CAD NOMINAL: geometry measured from the final model; hardware interfaces may require ASSEMBLY ADJUST.

Fabrication - LEFT_GUIDE_FOOT_0 | F-188

## CUSTOM_LEFT_GUIDE_FOOT_0

Qty1 | Stock material - VERIFY ON HARDWARE | thickness/depth 5.000 mm

SIDE EDGE PROJECTION - X / DEPTH

Assembly datum XYZ: 46.587, -20.000, 134.390

VERIFIED CAD NOMINAL: geometry measured from the final model; hardware interfaces may require ASSEMBLY ADJUST.

Fabrication - LEFT_GUIDE_HANGER_0 | F-189

## CUSTOM_LEFT_GUIDE_HANGER_0

Qty1 | PVC foam / Fomex | thickness/depth 5.000 mm

SIDE EDGE PROJECTION - X / DEPTH

Assembly datum XYZ: 46.587, -20.000, 134.390

VERIFIED CAD NOMINAL: geometry measured from the final model; hardware interfaces may require ASSEMBLY ADJUST.

DXF through-cut profile supplied; units mm, arc tolerance0.01; no kerf allowance.

Fabrication - LEFT_GUIDE_ANGLE_0 | F-190

## CUSTOM_LEFT_GUIDE_ANGLE_0

Qty1 | Stock material - VERIFY ON HARDWARE | thickness/depth 30.000 mm

SIDE EDGE PROJECTION - X / DEPTH

Assembly datum XYZ: 46.587, -20.000, 141.390

VERIFIED CAD NOMINAL: geometry measured from the final model; hardware interfaces may require ASSEMBLY ADJUST.

Fabrication - LEFT_GUIDE_BUSH_0 | F-191

## CUSTOM_LEFT_GUIDE_BUSH_0

Qty1 | Stock material - VERIFY ON HARDWARE | thickness/depth 10.000 mm

SIDE EDGE PROJECTION - X / DEPTH

Assembly datum XYZ: 58.087, -28.000, 82.500

VERIFIED CAD NOMINAL: geometry measured from the final model; hardware interfaces may require ASSEMBLY ADJUST.

Fabrication - LEFT_STOPPER_0 | F-192

## CUSTOM_LEFT_STOPPER_0

Qty1 | Stock material - VERIFY ON HARDWARE | thickness/depth 9.000 mm

SIDE EDGE PROJECTION - X / DEPTH

Assembly datum XYZ: 55.587, -20.000, 80.000

VERIFIED CAD NOMINAL: geometry measured from the final model; hardware interfaces may require ASSEMBLY ADJUST.

Fabrication - LEFT_GUIDE_FOOT_1 | F-193

## CUSTOM_LEFT_GUIDE_FOOT_1

Qty1 | Stock material - VERIFY ON HARDWARE | thickness/depth 5.000 mm

SIDE EDGE PROJECTION - X / DEPTH

Assembly datum XYZ: 203.353, -20.000, 134.390

VERIFIED CAD NOMINAL: geometry measured from the final model; hardware interfaces may require ASSEMBLY ADJUST.

Fabrication - LEFT_GUIDE_HANGER_1 | F-194

## CUSTOM_LEFT_GUIDE_HANGER_1

Qty1 | PVC foam / Fomex | thickness/depth 5.000 mm

SIDE EDGE PROJECTION - X / DEPTH

Assembly datum XYZ: 203.353, -15.000, 72.000

VERIFIED CAD NOMINAL: geometry measured from the final model; hardware interfaces may require ASSEMBLY ADJUST.

DXF through-cut profile supplied; units mm, arc tolerance0.01; no kerf allowance.

Fabrication - LEFT_GUIDE_ANGLE_1 | F-195

## CUSTOM_LEFT_GUIDE_ANGLE_1

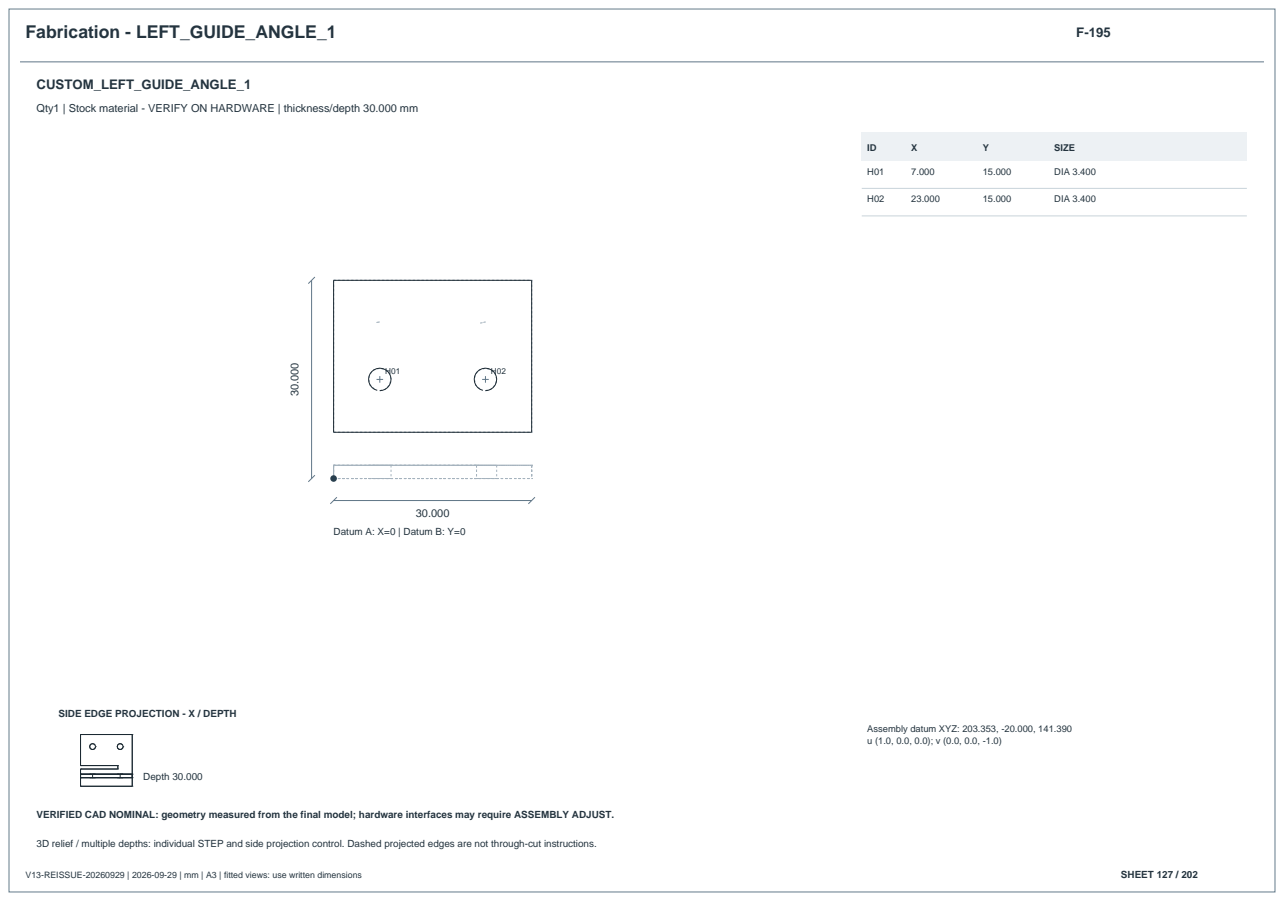
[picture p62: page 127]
V13-REISSUE-20260929 | 2026-09-29 | mm | A3 | fitted views: use written dimensions; SHEET 127 / 202; Datum A: X=0 | Datum B: Y=0; SIZE; DIA 3.400; Depth 30.000

Qty1 | Stock material - VERIFY ON HARDWARE | thickness/depth 30.000 mm

SIDE EDGE PROJECTION - X / DEPTH

Assembly datum XYZ: 203.353, -20.000, 141.390

VERIFIED CAD NOMINAL: geometry measured from the final model; hardware interfaces may require ASSEMBLY ADJUST.

Fabrication - LEFT_GUIDE_BUSH_1 | F-196

## CUSTOM_LEFT_GUIDE_BUSH_1

Qty1 | Stock material - VERIFY ON HARDWARE | thickness/depth 10.000 mm

SIDE EDGE PROJECTION - X / DEPTH

Assembly datum XYZ: 214.853, -28.000, 82.500

VERIFIED CAD NOMINAL: geometry measured from the final model; hardware interfaces may require ASSEMBLY ADJUST.

Fabrication - LEFT_STOPPER_1 | F-197

## CUSTOM_LEFT_STOPPER_1

Qty1 | Stock material - VERIFY ON HARDWARE | thickness/depth 9.000 mm

SIDE EDGE PROJECTION - X / DEPTH

Assembly datum XYZ: 212.353, -20.000, 80.000

VERIFIED CAD NOMINAL: geometry measured from the final model; hardware interfaces may require ASSEMBLY ADJUST.

Fabrication - LEFT_SWITCH_BRACKET | F-198

## CUSTOM_LEFT_SWITCH_BRACKET

Qty1 | PVC foam / Fomex | thickness/depth 5.000 mm

SIDE EDGE PROJECTION - X / DEPTH

Assembly datum XYZ: 117.970, -20.000, 134.390

VERIFIED CAD NOMINAL: geometry measured from the final model; hardware interfaces may require ASSEMBLY ADJUST.

DXF through-cut profile supplied; units mm, arc tolerance0.01; no kerf allowance.
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

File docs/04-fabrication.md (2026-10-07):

> MEASURED_LAYOUT_20261006 기준입니다. [필수 확인과 현장 조정](15-needed-measurements.md)을 구분해 진행합니다.

# 재단·가공 가이드

현재는 종이 대조·실측 단계입니다. 혼 연결, 기존 체결부 간섭, 포맥스 강도와 실제 체결품을 확인한 뒤 재단도를 확정합니다.

## 지금 할 일

1. [최신 PDF](../drawings/measurements-20261006/HELM_CURRENT_FLAT_PROFILES_REVIEW_A3.pdf)를 A3·실제 크기 100%로 출력합니다. 20쪽 모두 검토용이며 페이지 맞춤은 해제합니다.
2. 기준선을 재어 100 mm인지 확인합니다.
3. [섀시 기준 4홀 확인지](../drawings/measurements-20261006/HELM_CHASSIS_4HOLE_CHECK_A3.pdf)를 대조하고 실제 혼·필수 장착부만 확인합니다. 고정 꺽쇠의 홀은 현장에서 전사합니다.
4. 차이가 있으면 CAD를 수정합니다. 임의로 구멍을 늘려 끼우지 않습니다.

## 확정 뒤 가공 순서

부품명·리비전·STEP/DXF·두께 맞추기 → 판재에 번호/앞면/기준 모서리 표시 → 시험 조각에서 절삭 폭/구멍 확인 → 판 고정 → 절단/천공 → 줄·사포 마감 → 가조립·측정 기록.

- 구매한 5T 포맥스 600×900 mm 2장이 기준입니다. 현재 128개 제작 부품이 모두 두 장에서 단순 절단되는 부품이라는 뜻은 아닙니다.
- 3D 브래킷의 최대 깊이를 평판 두께로 오인하지 않습니다. 홈·단차는 STEP으로 확인합니다.
- V13 PDF를 종이에 대고 재단하지 않습니다. DXF에는 공구 경로나 절삭 폭이 반영되지 않았습니다.
- 전체 판재 배치/수량 최적화는 미완료입니다. 공구 여유는 시험 조각 결과를 반영합니다.
- 판을 받침판에 고정하고 보유 칼·톱으로 나누어 가공합니다. 손으로 들고 천공하지 않습니다.
- Bosch 2607010529 구성은 2/3/4/5/6/8 mm입니다. D4.5 도면과 맞지 않으므로 가공법과 설계를 함께 확정합니다. 임의로 D5로 넓히지 않습니다.
- 전산볼트는 고정해 자르고 끝단을 정리하며, 미리 끼운 너트로 나사산 통과를 확인합니다. 실물 너트·와셔에 맞춰 길이를 확정합니다.

포맥스 플랜지 주변의 좁은 부분, 너트의 직접 지지와 구멍 가장자리 남는 폭은 강도 검토 대상입니다. 보유 금속 브래킷 호환 확인 전에는 평판 검토 형상을 최종 하중 지지구조로 확정하지 않습니다.

전원 백플레이트 등 깊이 형상은 STEP으로 확인합니다. 20개 평면 도면 중 CUSTOM_5V_DISTRIBUTOR는 1.6 mm 가정 분배기판으로 5T 포맥스 가공 대상이나 확정 회로 제작 도면이 아닙니다. [현재 파일](03-cad.md)을 기준으로 재료·수량을 대조합니다.

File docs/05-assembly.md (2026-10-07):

# 조립 순서

현재 MEASURED_LAYOUT_20261006 기준의 가조립 순서입니다. 전원 분리 상태에서 기구 장착·배선 식별을 진행합니다.

| 순서 | 작업 | 확인할 것 |
|---|---|---|
| 1 | 확정 부품 가공·마감 | 번호·두께·리비전 |
| 2 | 섀시·하부 프레임 가조립 | 기존 체결홀·패드·하부판·지지봉 |
| 3 | 배터리·전원 백플레이트 | 스토퍼·스트랩·단자 접근·후면 인출 |
| 4 | 상부 데크·패널 | 와셔 지지·너트·서비스 면 접근 |
| 5 | 제어부·센서 | 실물 홀·스페이서·커넥터 방향 |
| 6 | LiDAR 타워 | 수평·지지·배선·스캔 영역 |
| 7 | 카메라·고정 열화상 | 최신 모터 기준, 혼·간섭 해결 후 |
| 8 | 범퍼·스위치·조작부 | 이동·복귀·스위치 동작 |
| 9 | 하네스 가배치 | 궤도·가동부·모서리·플러그 접근 |
| 10 | 전기 확인·단계별 시험 | 측정값과 판정 기록 |

기존 배터리 설계는 두 스트랩과 뒤쪽 -X 인출을 의도합니다. 보유 벨크로/스트랩의 수량·폭·길이, 단자 접근, 배선 후 인출 가능 여부를 확인합니다.

카메라는 새 모터 몸체·지지부 검사와 별개로 기존 볼트·너트 간섭이 남아 있습니다. [부품별 위치](10-open-items.md)를 확인하세요. 혼 없이 모터가 구조를 구동한다고 가정하지 않습니다.

최종 조임 전 손으로 천천히 움직여 걸림, 공구 접근과 케이블 여유를 봅니다. 재료별 조건이 확정되지 않은 상태에서 일괄 체결 토크를 임의 지정하지 않습니다.

C715는 실제 2280 슬롯·끝단 지지에 맞춰 방향과 보유 나사를 확인합니다. CP003 외곽은 실측과 맞습니다. 고정홀은 실물 배치 후 전사하고 덮개·공구·절연 여유를 확인합니다. 내부 단자 배정과 전기 검증 전에는 결선을 확정하지 않습니다. ADS1115 받침은 제거했으므로 과거 도면대로 만들지 않습니다. [추가 치수](15-needed-measurements.md)를 반영한 뒤 최종 조립도를 확정합니다.

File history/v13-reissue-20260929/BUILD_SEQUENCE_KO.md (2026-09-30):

# CAD 및 설계도 재생성 순서

전체 폴더를 복사한 작업본에서 아래 명령을 순서대로 실행하세요. Python, CadQuery/OpenCascade, NumPy, ezdxf, ReportLab, PyMuPDF, Pillow와 g++가 필요합니다. 사용한 버전은 GENERATION_RECORD.json에 있습니다.

```bash
python HELM_V13_WORK/export_latest.py
python HELM_V13_WORK/validate_final_step.py
python HELM_V13_WORK/prepare_drawings.py
python HELM_V13_WORK/drawings.py
python finalize_generated_release.py
```

첫 단계는 후보 STEP을 생성하고 두 번째 단계가 통과하면 HELM_V13_LATEST.step으로 확정합니다. prepare_drawings.py는 제작 부품 STEP·DXF·치수 데이터를 출력합니다. 현재 형상을 유지하는 재출력에서는 기존 메시·뷰 캐시를 재사용합니다. 형상을 바꾼 작업본에서는 HELM_V13_DRAWINGS/DATA/mesh.npz와 VIEWS 폴더의 캐시를 지우고, manifest의 경계 좌표·면·솔리드 개수 및 INPUT_BREP_SHA256.json을 새 기준에 맞게 갱신한 뒤 필요한 형상·간섭·가동 검사를 수행해야 합니다.

drawings.py는 통합 PDF와 표를 생성합니다. finalize_generated_release.py는 가공 파일과 PDF를 검사하고 모든 페이지를 200 dpi PNG로 출력합니다. 시각 검토 완료를 DRAWING_VALIDATION.json의 visual_review에 기록한 다음 package_regenerated_release.py로 ZIP을 만듭니다.

HELM_V13_WORK에는 과거 수정 코드도 보존되어 있습니다. 위 목록 외의 수정 스크립트 전체를 일괄 실행하지 마세요. 현재 수정 없이 재출력하는 경우 기존 기준 파일과 검증 범위를 그대로 유지합니다.

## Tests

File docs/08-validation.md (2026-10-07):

# 현재 검증 결과

MEASURED_LAYOUT_20261006. 제작 승인 보류입니다.

| 검사 | 결과 |
|---|---|
| 변경부 정지 | 후보 80쌍, 0.5 mm³ 초과 겹침 24쌍. C920 내부 참조 4쌍 포함 |
| 카메라 | 9개 자세의 겹침 수 8,2,4,8,2,4,8,2,4, 고유 10쌍 잔류 |
| 변경 STEP 26개 | 재읽기 유효, 경계 오차 0.002 mm 미만 |
| 제작 STEP 128개 | 재읽기 유효, 경계 오차 0.002 mm·상대 부피 차이 0.01% 미만 |
| 전체 STEP | 371,507,206바이트, 5,050,704엔티티. 모델 이름 3,888개 누락 없음. 형상 재전송은 변경 26개 범위 |
| 편집 복원 | 기준본과 델타로 편집 파일 3,897개 SHA-256 일치 |
| 부품 매핑 | 93개 구매 행·13개 치수 기록·3,888개 CAD 노드 |
| 문서 | 가이드 6쪽·윤곽 20쪽·기준 홀 1쪽, Excel 6개 시트 표시 확인 |

팬 ±45°·틸트 ±20°는 검사한 자세이며 승인 동작 범위가 아닙니다. 160개 구형 꺽쇠 체결 형상을 생략했으므로 이전 15쌍에서 10쌍으로 줄어든 것을 안전성 개선으로 해석하지 않습니다.

미변경 정지 부품 전체 쌍·연속 회전·공차·유연 배선·혼·강도·하중·실제 조립 작동은 포함하지 않았습니다. CAD 유효성과 제조 승인은 다릅니다.

[겹침 목록](10-open-items.md) · [현재 검사](../data/measurements-20261006/VALIDATION.json) · [STEP 재읽기](../data/measurements-20261006/FULL_STEP_READBACK.json) · [부품 오차](../data/measurements-20261006/FABRICATION_INDEX.json)

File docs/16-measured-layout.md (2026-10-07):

# HELM 실측 반영 CAD

**MEASURED_LAYOUT_20261006 · 3,888개 노드 · 재단·통전 승인 전 검토 조립체**

실측 기록을 전체 CAD에 반영한 파일입니다. 구매 93개 행과 CAD 노드, 실측 기록 13개를 연결했습니다. 정확한 치수가 필요한 연결부와 회전부가 남아 있어 최종 제조 승인본은 아닙니다.

## 파일 열기

- `CAD/HELM_MEASURED_COMPACT.step`: 전체 조립체. STEP 지원 CAD에서 mm 단위로 여세요.
- `EDITABLE/HELM_WORK`: 전체 3,888개 BREP와 그룹·포트·배선·조인트 정보.
- `HELM_부품번호_실측적용표.xlsx`: 전체번호 93개, 실측기록 13개, 필수확인, 현장조정, CAD노드, 출처.
- `DRAWINGS/HELM_MEASURED_BUILD_GUIDE_KO.pdf`: 실측 적용·재단·조립 가이드 6쪽.
- `DRAWINGS/HELM_CURRENT_FLAT_PROFILES_REVIEW_A3.pdf`: 1:1 윤곽 검토도 20쪽.
- `DRAWINGS/HELM_CHASSIS_4HOLE_CHECK_A3.pdf`: 섀시 기준 4홀 1:1 종이 대조 양식.
- `FABRICATION_STEP`: 제작 후보 128개. 전부 포맥스 재단품은 아닙니다.
- `DXF_REVIEW_ONLY`: 일정 두께 윤곽 20개. 19개는 5T, 1개는 1.6T 분배기판 참조입니다.
- `PART_STEP`: 변경 형상 26개. `OPTIONAL_INVENTORY_STEP`의 3개는 선택 재고 외접 상자입니다.
- `EVIDENCE`: 받은 치수표 원본과 삽입 사진. `DATA`: 매핑·치수·검증 원자료.

## 재단 전에 확인할 내용

1. SER0063에 사용할 실제 혼의 홀·두께·장착 높이. 몸체는 재측정하지 않으셔도 됩니다.
2. 비상정지 스위치 장착 지름·5T 체결 길이·후면 돌출. 시험 끼움으로 확인 가능합니다.
3. 섀시 기준 4홀과 실제 판 두께·적층 높이. 1:1 종이와 실물이 맞으면 전체 재측정은 불필요합니다.
4. 범퍼 스위치 작동점·복귀 기능과 실제 스프링·가이드 보유 여부.

로커는 5T 자투리에 Ø20부터 시험하고, Ø27 테두리 치수로 본판을 뚫지 않습니다. MG995 프레임은 회전축·하중 부품으로 채택할 때만 내측·홀·두께를 확인합니다. 카메라 꺽쇠·체결품은 실제 혼을 정한 뒤 간섭 수정이 필요합니다.

고정 꺽쇠·CP003 홀은 실물 전사, 스페이서·전산볼트는 가조립 높이, 벨크로·EVA·배선은 현장 여유에 맞춰 조정합니다. 작은 칩은 개별 측정하지 않습니다. PCB 홀을 넓히거나 강제로 끼우지 않습니다.

## 남은 설계 범위

변경부 후보 80쌍 중 0.5 mm³ 초과 겹침 24쌍을 기록했으며 C920 내부 참조 4쌍을 포함합니다. 카메라 9개 자세 검사에는 고유 10쌍이 남아 있습니다. 상세 목록은 `DOCS/collision-register.md`입니다. 가정 체결품을 제거한 것은 간섭 해결이나 체결 완료가 아닙니다.

보유 판재는 **5T 포맥스 600×900 mm 2장**입니다. 최종 네스팅·강도·케이블 동작·결선은 아직 승인되지 않았습니다. 소형 꺽쇠·스프링·가이드·소형 나사·일부 받침과 분배기판의 실제 보유 여부도 구분되어 있습니다.

## 이전 자료와 적용 순서

같은 리비전의 CAD·치수표·검증을 우선합니다. 과거 FINAL/PASS와 “디자인 변경·검색 불필요”는 당시 확인한 본체와 범위에 한정합니다. 실제 부품과 다르면 해당 연결부를 수정합니다. `LIB_SER0063.zip`은 모터 몸체 CAD이며 혼은 포함하지 않습니다.

재생성은 현재 BREP에 `SOURCE/export_compact_snapshot.py`를 사용합니다. `build_measured_cad.py`는 변경 전 PROCUREMENT_REVIEW_20261001 입력에만 적용하며 현재 형상에 반복 적용하지 않습니다. compact STEP은 중복된 2D 곡선 표현을 생략한 3D STEP으로, 형상 축척을 줄인 파일이 아닙니다.

라이선스와 출처는 `LICENSE`, `SOURCE/NOTICES.md`에 보존했습니다. 전체 파일 SHA-256은 `PACKAGE_SHA256.json`에 있습니다.

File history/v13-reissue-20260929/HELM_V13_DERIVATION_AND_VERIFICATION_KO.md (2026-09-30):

# HELM V13 최종 CAD 제작 및 설계도 도출

리비전 **V13-REISSUE-20260929** / 2026-09-29

제공된 인계 자료의 확정 편집 BREP에서 최종 조립체 STEP, 제작 부품 STEP, 가공용 DXF, 치수 데이터와 통합 설계도 PDF를 새로 생성했습니다. 이번 작업에서는 실제 형상과 배치를 변경하지 않았습니다.

## 산출물

| 파일 | 수량·내용 | ZIP 내부 위치 |
| --- | --- | --- |
| 최종 조립체 STEP | 4,102개 이름 있는 제품 노드 | `HELM_V13_DELIVERY/HELM_V13_LATEST.step` |
| 제작 부품 STEP | 130개, 원래 조립체 좌표 보존 | `HELM_V13_DRAWINGS/PART_STEP/` |
| 가공용 DXF | 54개, mm 단위의 관통 절단 윤곽 | `HELM_V13_DRAWINGS/DXF/` |
| 통합 설계도 PDF | A3 가로 202쪽 | `HELM_V13_DRAWINGS/HELM_FULL_FABRICATION_AND_ASSEMBLY_DRAWING.pdf` |
| 페이지 PNG | 202개, 200 dpi | `HELM_V13_DRAWINGS/PNG/` |
| 홀·개구부 좌표 | 616개 특징 | `HELM_V13_DRAWINGS/HOLE_COORDINATES.csv` |
| BOM·체결품·배선표 | 각 237·33·49개 행 | `HELM_V13_DRAWINGS/`의 CSV 파일 |
| 부품-노드 연결표 | 4,102개 행 | `HELM_V13_DRAWINGS/PART_NODE_MAPPING.csv` |
| 편집 자료와 생성 코드 | BREP, 부품·판재·배선 데이터, Python 코드 | `HELM_V13_WORK/` |

## 수행 과정

1. 인계 ZIP의 SHA-256을 확인하고 편집 자료를 복원했습니다. 입력 BREP 4,102개의 해시를 기록했습니다.
2. 기존 전체 부품 기록 대조에서 발견한 열화상 카메라 지지부 3개의 오래된 경계 좌표·면 개수를 실제 BREP 기준으로 정정했습니다. 원본 목록과 이전 값은 `SOURCE_REQUIREMENTS/ORIGINAL_MANIFEST_BEFORE_METADATA_REFRESH.json` 및 `METADATA_REFRESH.json`에 보존했습니다.
3. 부품 이름·그룹·색상·배치를 유지하고 p-curve를 포함한 최종 조립체 STEP을 출력했습니다.
4. 새 STEP의 전체 제품 구조를 다시 읽고, 이전 기준본에서 변경된 부품과 이웃 23개 형상 및 인접 조합 27개를 검사했습니다.
5. 제작 대상 130개에서 기준면·외곽·깊이·홀·슬롯을 추출하여 개별 STEP을 출력했습니다. 일정 두께 관통 절단 대상 54개에는 DXF를 생성했습니다.
6. 치수·배치·연결점·배선 자료로 202쪽 PDF와 도면 목차·BOM·체결품·배선표를 생성했습니다. 표지와 도면 데이터에 새 STEP 해시를 연결했습니다. 시각화용 메시와 음영 뷰는 동일 원본의 캐시를 재사용했습니다.
7. 부품 STEP 전부를 재읽고 DXF를 검사했습니다. PDF 목차·페이지·문자 영역을 검사하고 202개 PNG를 출력·확인했습니다. 전체 페이지 축소 보기와 주요 상세 페이지를 시각 검토했습니다.
8. CAD·도면·편집 원본·생성 코드·검증 기록을 ZIP으로 묶고 압축 무결성을 검사했습니다.

## 검증 결과

| 항목 | 결과 |
| --- | --- |
| 입력 형상 | 4,102개 BREP 해시 불변 |
| STEP 제품 구조 | 4,102개 일치 |
| STEP 국소 형상 | 23개 형상 유효성·솔리드·경계 좌표 검사 통과 |
| 국소 간섭 | 27개 조합, 교차 체적 0.5 mm³ 초과 0건 |
| 부품 STEP | 130개 재읽기 통과 |
| 부품 재읽기 오차 | 최대 상대 부피 오차 3.83e-06, 경계 좌표 오차 1.2e-06 mm |
| 치수·기준점·홀 좌표 | 기존 도출 자료와 일치 |
| DXF | 54개 단위·형상 존재·구조 검사 통과 |
| PDF·PNG | 202쪽 목차·문자 영역 검사, 202개 PNG 구조 검사 통과 |

`STEP_VALIDATION.json`의 변경 부품 12개는 역사적 기준본과의 차이입니다. 이번 재출력에서 해당 부품을 새로 수정한 것은 아닙니다. 기존 전체 조립체·가동 범위 검사 결과는 `HELM_V13_DELIVERY/history/` 및 `HELM_V13_DELIVERY/VALIDATION/FINAL_MOTION_BASELINE.json`에 보존했습니다. 이번에는 전체 가동 해석·모든 부품 조합 간섭 검사·실물 시험을 반복하지 않았습니다.

## 도면 구성

| PDF 페이지 | 내용 |
| --- | --- |
| 1-18 | 표지·목차·전체도·6면도·배치·분해도·프레임 |
| 19-162 | 제작 부품 치수 및 홀 좌표 |
| 163-173 | 체결·카메라·LiDAR·범퍼·배터리 상세 |
| 174-186 | 전원·신호·물리 배선·서비스 접근·실물 확인 항목 |
| 187-200 | BOM 및 체결품 |
| 201-202 | 조립 순서와 제작 전 점검 |

정확한 가공 윤곽과 비관통 형상은 STEP을 기준으로 하세요. DXF는 해당 파일이 제공된 관통 절단 부품에만 사용합니다. 단위는 mm, 곡선 근사 허용값은 0.01 mm이며 절삭 폭 보정은 포함하지 않았습니다. CAD 공칭 치수와 실제 가공 공차는 별개입니다.

## 실물 확인이 남은 항목

PDF **183쪽 E-211**에 LiDAR 인터페이스·케이블 경로, ADC 실장 모듈·전원·핀맵, 전압 측정 보조 퓨즈, 서보 전원 조건의 확인 사항을 표시했습니다. 커넥터·모터·엔코더 핀맵, 극성, 릴레이·E-STOP 동작, 케이블 굽힘·고정, 구매품 체결홀, 배터리 후면 인출, 재료·와셔 지지와 서보 하중도 실물 확인 대상입니다. 파일 검증 결과는 실물 제작·전기·하중 시험의 승인을 대신하지 않습니다.

## 재생성과 무결성 확인

실행 순서는 `BUILD_SEQUENCE_KO.md`, 버전과 검사 기록은 `GENERATION_RECORD.json` 및 각 `VALIDATION/` 폴더에 있습니다. 전체 파일 해시는 `SHA256SUMS.txt`에서 확인하세요.

최종 STEP SHA-256: `6942914ab1ea14b2dece5bdde453c85a6a909255873ff5ab9afa32673fce11da`

통합 PDF SHA-256: `fb1144bef82c466c8826ebd84203491135ca084694bc93670a23394a3aa206f6`

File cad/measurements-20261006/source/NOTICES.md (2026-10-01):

# Source provenance

The original HELM repository LICENSE is preserved. Third-party manufacturer CAD and product photos retain their original ownership/notices; no new license grant is asserted.

SEENGREAT manufacturer model: https://seengreat.com/wiki/88/thermal-camera-mlx90640-d55
Downloaded archive: https://seengreat.com/upload/file/88/Thermal%20Camera%20HAT-V1.2.zip
Stored STEP SHA-256: 5623f4aba40f299465756719ec73b9ef6cf0a6151bb10656da6c709e14155c59

SER0063 derives from the user-supplied motor CAD, preserved under rigid transforms with no scaling. Earlier native chassis, NVIDIA and other manufacturer parts retain their source metadata in DATA/manifest.json. Evidence captures come from the supplied purchase workbook and identified seller. See DOCS/14-product-photo-review.md and EVIDENCE/PROVENANCE.json.

The PDFs embed a subset of Noto Sans KR. The standalone font is not included; regeneration accepts a Korean TTF path.

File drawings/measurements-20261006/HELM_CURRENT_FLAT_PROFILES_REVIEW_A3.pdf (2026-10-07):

## HELM / 현재 형상에서 추출한 평면 윤곽

# CUSTOM_BATTERY_PLATE

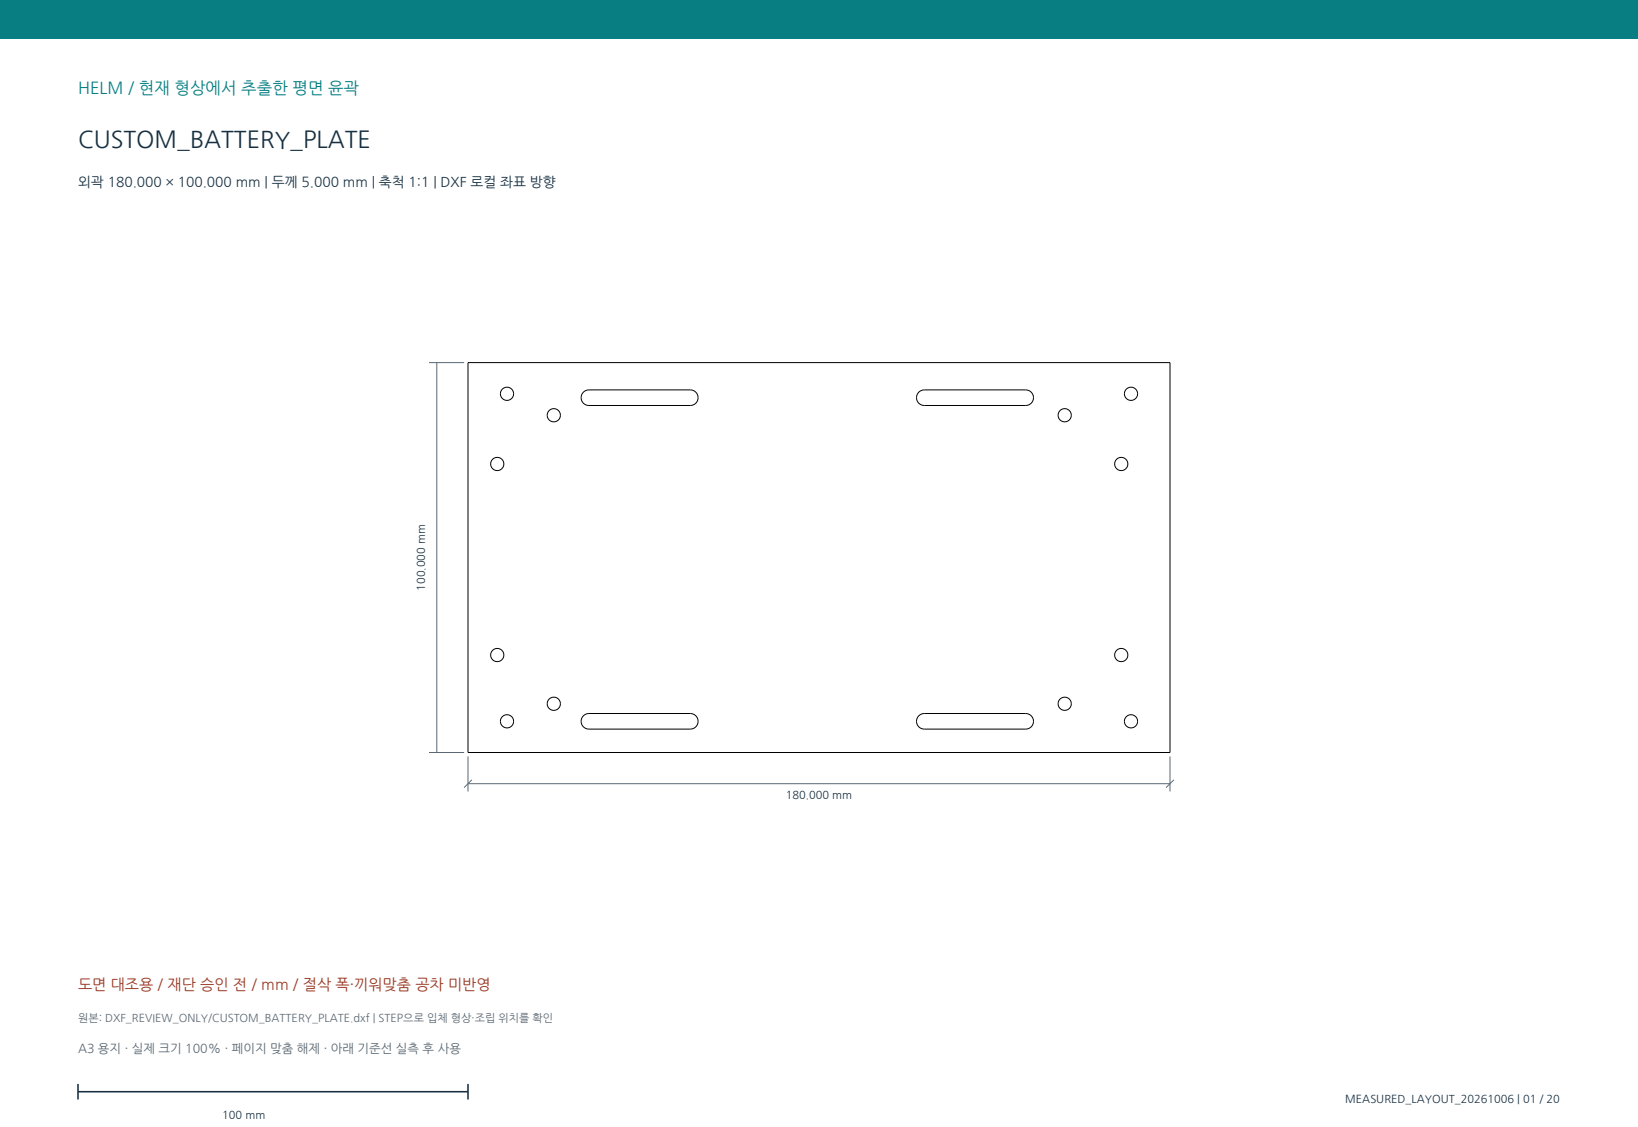
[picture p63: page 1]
MEASURED_LAYOUT_20261006 | 01 / 20

외곽 180.000 × 100.000 mm | 두께 5.000 mm | 축척 1:1 | DXF 로컬 좌표 방향

도면 대조용 / 재단 승인 전 / mm / 절삭 폭·끼워맞춤 공차 미반영

원본: DXF_REVIEW_ONLY/CUSTOM_BATTERY_PLATE.dxf | STEP으로 입체 형상·조립 위치를 확인

A3 용지 · 실제 크기 100% · 페이지 맞춤 해제 · 아래 기준선 실측 후 사용

# CUSTOM_CHASSIS_PAD_0_1

### 외곽 20.000 × 20.000 mm | 두께 5.000 mm | 축척 1:1 | DXF 로컬 좌표 방향

20.000 mm

20.000 mm

## 도면 대조용 / 재단 승인 전 / mm / 절삭 폭·끼워맞춤 공차 미반영

원본: DXF_REVIEW_ONLY/CUSTOM_CHASSIS_PAD_0_1.dxf | STEP으로 입체 형상·조립 위치를 확인

A3 용지 · 실제 크기 100% · 페이지 맞춤 해제 · 아래 기준선 실측 후 사용

# CUSTOM_CHASSIS_PAD_1_1

### 외곽 20.000 × 20.000 mm | 두께 5.000 mm | 축척 1:1 | DXF 로컬 좌표 방향

20.000 mm

20.000 mm

## 도면 대조용 / 재단 승인 전 / mm / 절삭 폭·끼워맞춤 공차 미반영

원본: DXF_REVIEW_ONLY/CUSTOM_CHASSIS_PAD_1_1.dxf | STEP으로 입체 형상·조립 위치를 확인

A3 용지 · 실제 크기 100% · 페이지 맞춤 해제 · 아래 기준선 실측 후 사용

# CUSTOM_CHASSIS_PAD_2_1

### 외곽 20.000 × 20.000 mm | 두께 5.000 mm | 축척 1:1 | DXF 로컬 좌표 방향

20.000 mm

20.000 mm

## 도면 대조용 / 재단 승인 전 / mm / 절삭 폭·끼워맞춤 공차 미반영

원본: DXF_REVIEW_ONLY/CUSTOM_CHASSIS_PAD_2_1.dxf | STEP으로 입체 형상·조립 위치를 확인

A3 용지 · 실제 크기 100% · 페이지 맞춤 해제 · 아래 기준선 실측 후 사용

# CUSTOM_CHASSIS_PAD_3_1

### 외곽 20.000 × 20.000 mm | 두께 5.000 mm | 축척 1:1 | DXF 로컬 좌표 방향

20.000 mm

20.000 mm

## 도면 대조용 / 재단 승인 전 / mm / 절삭 폭·끼워맞춤 공차 미반영

원본: DXF_REVIEW_ONLY/CUSTOM_CHASSIS_PAD_3_1.dxf | STEP으로 입체 형상·조립 위치를 확인

A3 용지 · 실제 크기 100% · 페이지 맞춤 해제 · 아래 기준선 실측 후 사용

# CUSTOM_FRONT_PANEL

### 외곽 218.000 × 120.000 mm | 두께 5.000 mm | 축척 1:1 | DXF 로컬 좌표 방향

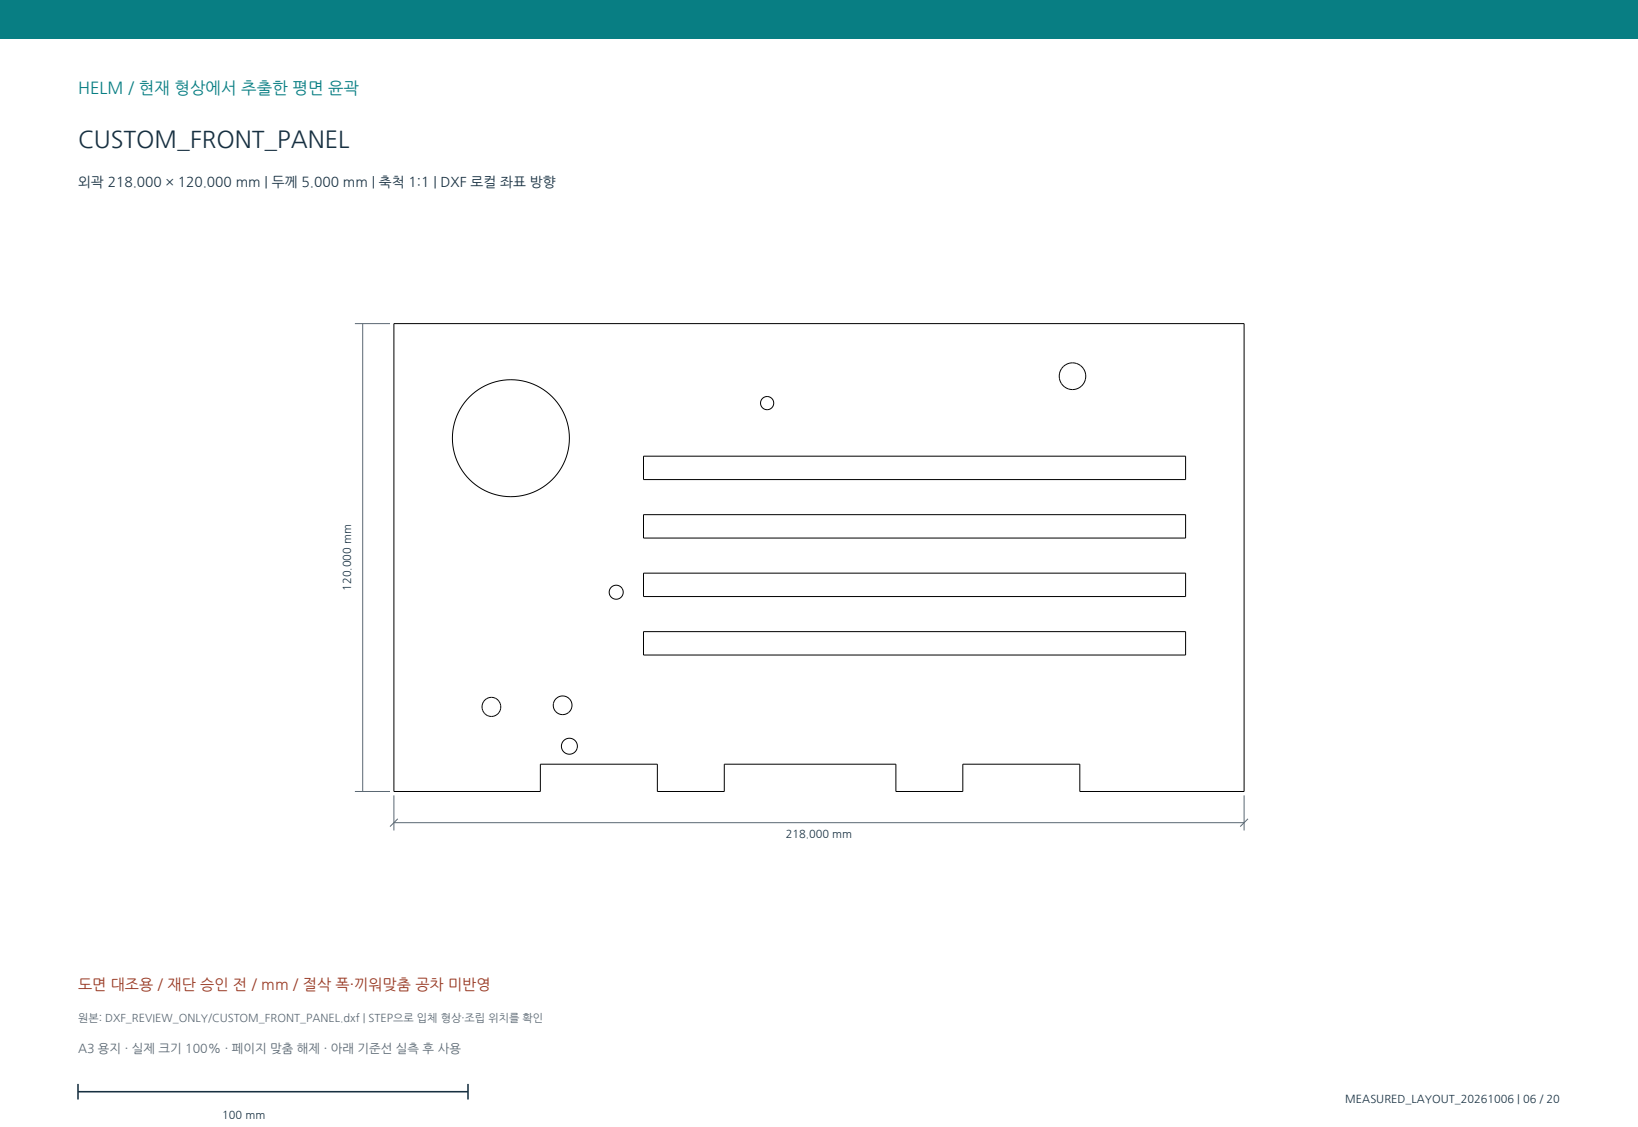
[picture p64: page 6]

도면 대조용 / 재단 승인 전 / mm / 절삭 폭·끼워맞춤 공차 미반영

원본: DXF_REVIEW_ONLY/CUSTOM_FRONT_PANEL.dxf | STEP으로 입체 형상·조립 위치를 확인

A3 용지 · 실제 크기 100% · 페이지 맞춤 해제 · 아래 기준선 실측 후 사용

# CUSTOM_LIDAR_BRIDGE

### 외곽 54.000 × 213.000 mm | 두께 5.000 mm | 축척 1:1 | 지면상 90도 회전

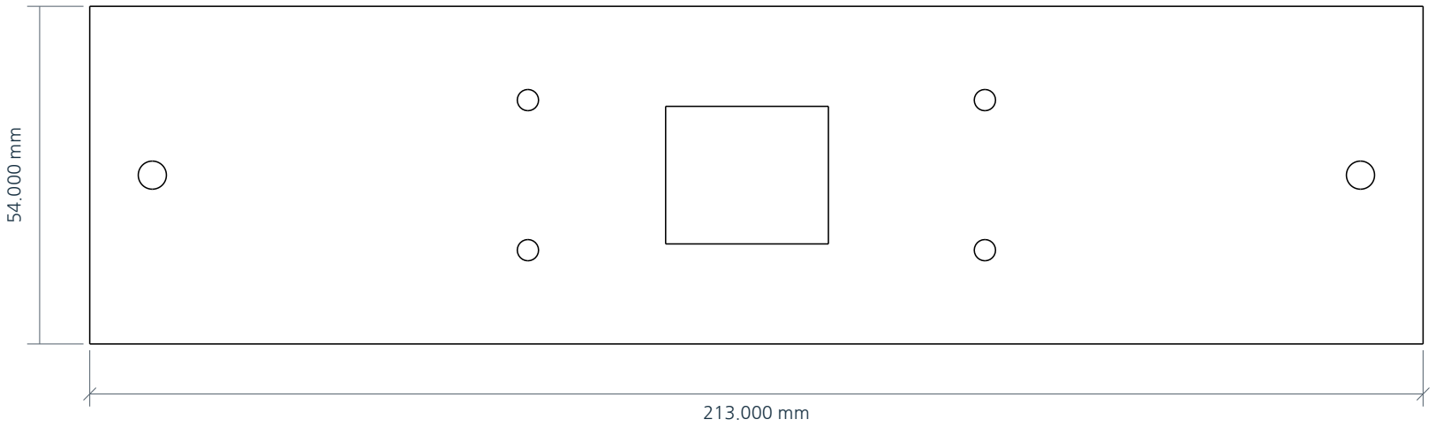
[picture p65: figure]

## 도면 대조용 / 재단 승인 전 / mm / 절삭 폭·끼워맞춤 공차 미반영

원본: DXF_REVIEW_ONLY/CUSTOM_LIDAR_BRIDGE.dxf | STEP으로 입체 형상·조립 위치를 확인

A3 용지 · 실제 크기 100% · 페이지 맞춤 해제 · 아래 기준선 실측 후 사용

# CUSTOM_LIDAR_PLATE

### 외곽 92.000 × 94.000 mm | 두께 5.000 mm | 축척 1:1 | DXF 로컬 좌표 방향

## 도면 대조용 / 재단 승인 전 / mm / 절삭 폭·끼워맞춤 공차 미반영

원본: DXF_REVIEW_ONLY/CUSTOM_LIDAR_PLATE.dxf | STEP으로 입체 형상·조립 위치를 확인

A3 용지 · 실제 크기 100% · 페이지 맞춤 해제 · 아래 기준선 실측 후 사용

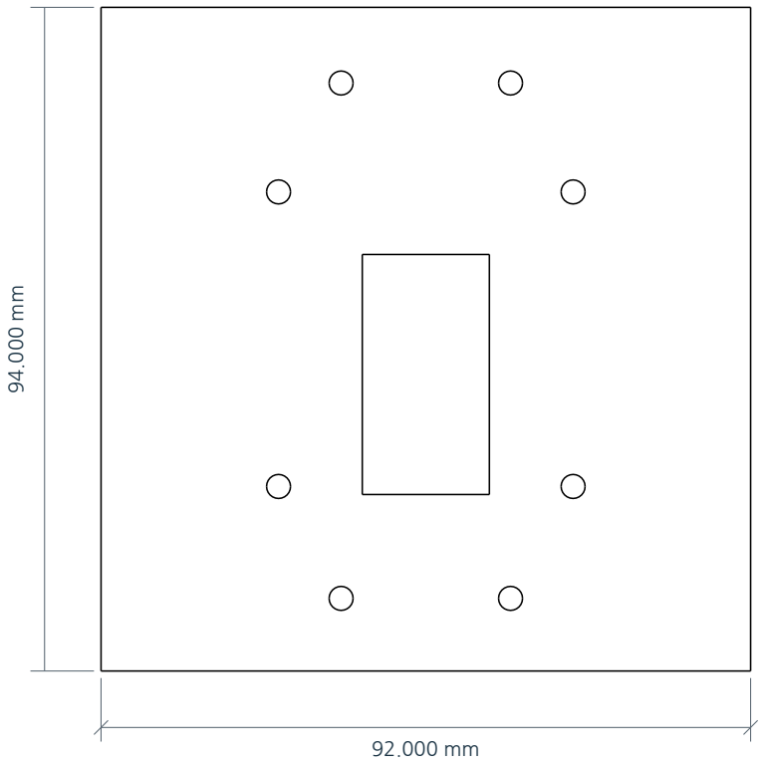
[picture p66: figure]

# CUSTOM_BATTERY_STOP_FRONT

### 외곽 5.000 × 73.000 mm | 두께 5.000 mm | 축척 1:1 | DXF 로컬 좌표 방향

5.000 mm

73.000 mm

## 도면 대조용 / 재단 승인 전 / mm / 절삭 폭·끼워맞춤 공차 미반영

원본: DXF_REVIEW_ONLY/CUSTOM_BATTERY_STOP_FRONT.dxf | STEP으로 입체 형상·조립 위치를 확인

A3 용지 · 실제 크기 100% · 페이지 맞춤 해제 · 아래 기준선 실측 후 사용

# CUSTOM_BATTERY_STOP_REAR

### 외곽 5.000 × 73.000 mm | 두께 5.000 mm | 축척 1:1 | DXF 로컬 좌표 방향

5.000 mm

73.000 mm

## 도면 대조용 / 재단 승인 전 / mm / 절삭 폭·끼워맞춤 공차 미반영

원본: DXF_REVIEW_ONLY/CUSTOM_BATTERY_STOP_REAR.dxf | STEP으로 입체 형상·조립 위치를 확인

A3 용지 · 실제 크기 100% · 페이지 맞춤 해제 · 아래 기준선 실측 후 사용

# CUSTOM_BATTERY_STOP_LEFT

### 외곽 155.000 × 5.000 mm | 두께 5.000 mm | 축척 1:1 | DXF 로컬 좌표 방향

155.000 mm

5.000 mm

## 도면 대조용 / 재단 승인 전 / mm / 절삭 폭·끼워맞춤 공차 미반영

원본: DXF_REVIEW_ONLY/CUSTOM_BATTERY_STOP_LEFT.dxf | STEP으로 입체 형상·조립 위치를 확인

A3 용지 · 실제 크기 100% · 페이지 맞춤 해제 · 아래 기준선 실측 후 사용

# CUSTOM_BATTERY_STOP_RIGHT

### 외곽 155.000 × 5.000 mm | 두께 5.000 mm | 축척 1:1 | DXF 로컬 좌표 방향

155.000 mm

5.000 mm

## 도면 대조용 / 재단 승인 전 / mm / 절삭 폭·끼워맞춤 공차 미반영

원본: DXF_REVIEW_ONLY/CUSTOM_BATTERY_STOP_RIGHT.dxf | STEP으로 입체 형상·조립 위치를 확인

A3 용지 · 실제 크기 100% · 페이지 맞춤 해제 · 아래 기준선 실측 후 사용

# CUSTOM_CAMERA_BASE

### 외곽 72.000 × 144.000 mm | 두께 5.000 mm | 축척 1:1 | DXF 로컬 좌표 방향

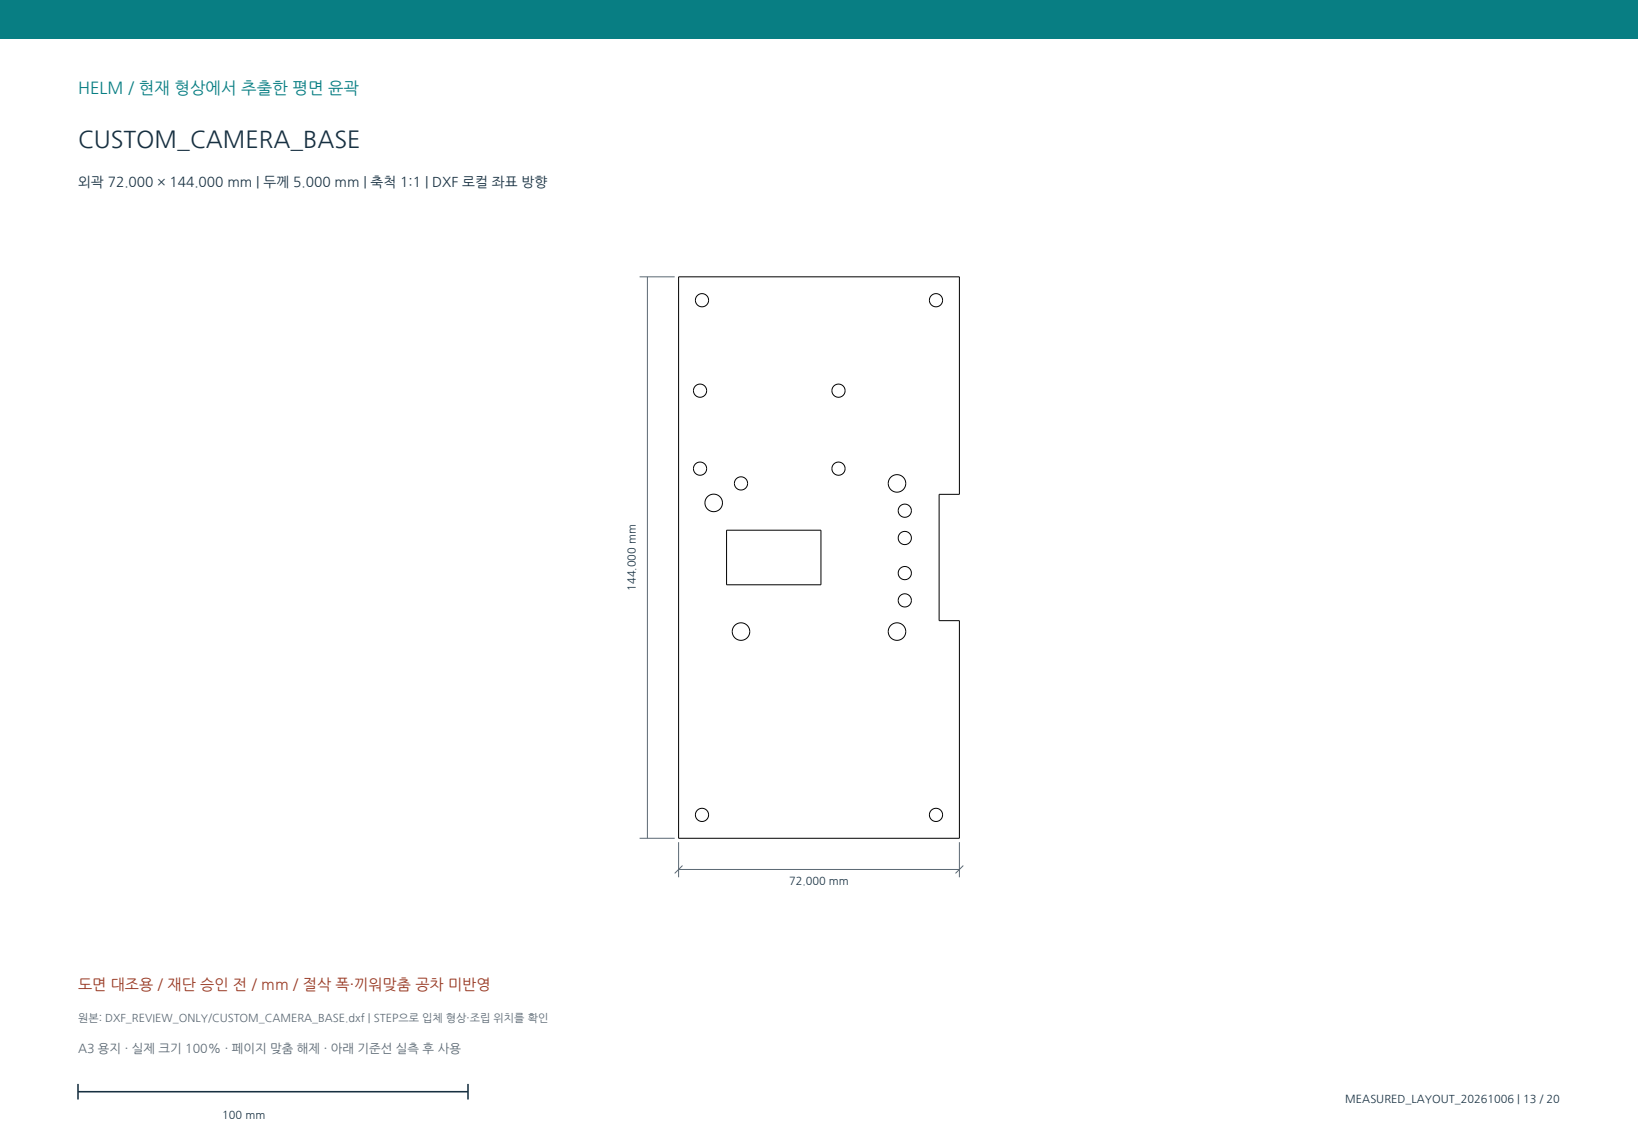
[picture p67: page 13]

도면 대조용 / 재단 승인 전 / mm / 절삭 폭·끼워맞춤 공차 미반영

원본: DXF_REVIEW_ONLY/CUSTOM_CAMERA_BASE.dxf | STEP으로 입체 형상·조립 위치를 확인

A3 용지 · 실제 크기 100% · 페이지 맞춤 해제 · 아래 기준선 실측 후 사용

# CUSTOM_PAN_ARM_LEFT

### 외곽 74.000 × 59.000 mm | 두께 5.000 mm | 축척 1:1 | DXF 로컬 좌표 방향

## 도면 대조용 / 재단 승인 전 / mm / 절삭 폭·끼워맞춤 공차 미반영

원본: DXF_REVIEW_ONLY/CUSTOM_PAN_ARM_LEFT.dxf | STEP으로 입체 형상·조립 위치를 확인

A3 용지 · 실제 크기 100% · 페이지 맞춤 해제 · 아래 기준선 실측 후 사용

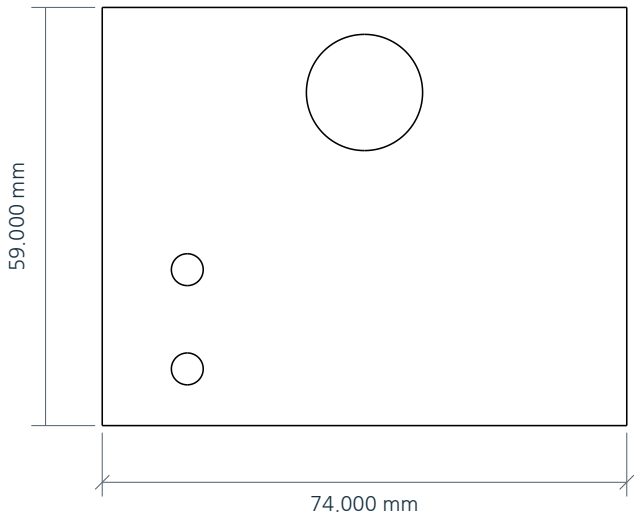
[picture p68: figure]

# CUSTOM_TILT_CHEEK_LEFT

### 외곽 70.000 × 50.000 mm | 두께 5.000 mm | 축척 1:1 | DXF 로컬 좌표 방향

70.000 mm

50.000 mm

## 도면 대조용 / 재단 승인 전 / mm / 절삭 폭·끼워맞춤 공차 미반영

원본: DXF_REVIEW_ONLY/CUSTOM_TILT_CHEEK_LEFT.dxf | STEP으로 입체 형상·조립 위치를 확인

A3 용지 · 실제 크기 100% · 페이지 맞춤 해제 · 아래 기준선 실측 후 사용

# CUSTOM_TILT_CHEEK_RIGHT

### 외곽 70.000 × 50.000 mm | 두께 5.000 mm | 축척 1:1 | DXF 로컬 좌표 방향

70.000 mm

50.000 mm

## 도면 대조용 / 재단 승인 전 / mm / 절삭 폭·끼워맞춤 공차 미반영

원본: DXF_REVIEW_ONLY/CUSTOM_TILT_CHEEK_RIGHT.dxf | STEP으로 입체 형상·조립 위치를 확인

A3 용지 · 실제 크기 100% · 페이지 맞춤 해제 · 아래 기준선 실측 후 사용

# CUSTOM_C920_SADDLE

### 외곽 70.000 × 104.800 mm | 두께 5.000 mm | 축척 1:1 | DXF 로컬 좌표 방향

## 도면 대조용 / 재단 승인 전 / mm / 절삭 폭·끼워맞춤 공차 미반영

원본: DXF_REVIEW_ONLY/CUSTOM_C920_SADDLE.dxf | STEP으로 입체 형상·조립 위치를 확인

A3 용지 · 실제 크기 100% · 페이지 맞춤 해제 · 아래 기준선 실측 후 사용

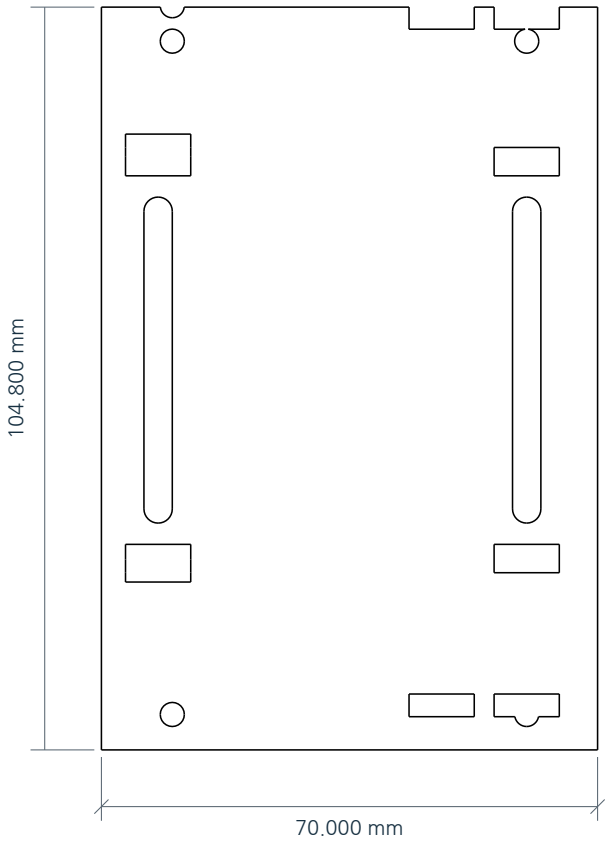
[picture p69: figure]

# CUSTOM_5V_DISTRIBUTOR

### 외곽 40.000 × 20.000 mm | 두께 1.600 mm | 축척 1:1 | DXF 로컬 좌표 방향

40.000 mm

20.000 mm

## 도면 대조용 / 재단 승인 전 / mm / 절삭 폭·끼워맞춤 공차 미반영

원본: DXF_REVIEW_ONLY/CUSTOM_5V_DISTRIBUTOR.dxf | STEP으로 입체 형상·조립 위치를 확인

주의: 1.6 mm 분배기판 형상 참조이며 포맥스 재단·회로 제작 승인 도면이 아닙니다.

# CUSTOM_PAN_SERVO_MOUNT

### 외곽 72.000 × 60.000 mm | 두께 5.000 mm | 축척 1:1 | DXF 로컬 좌표 방향

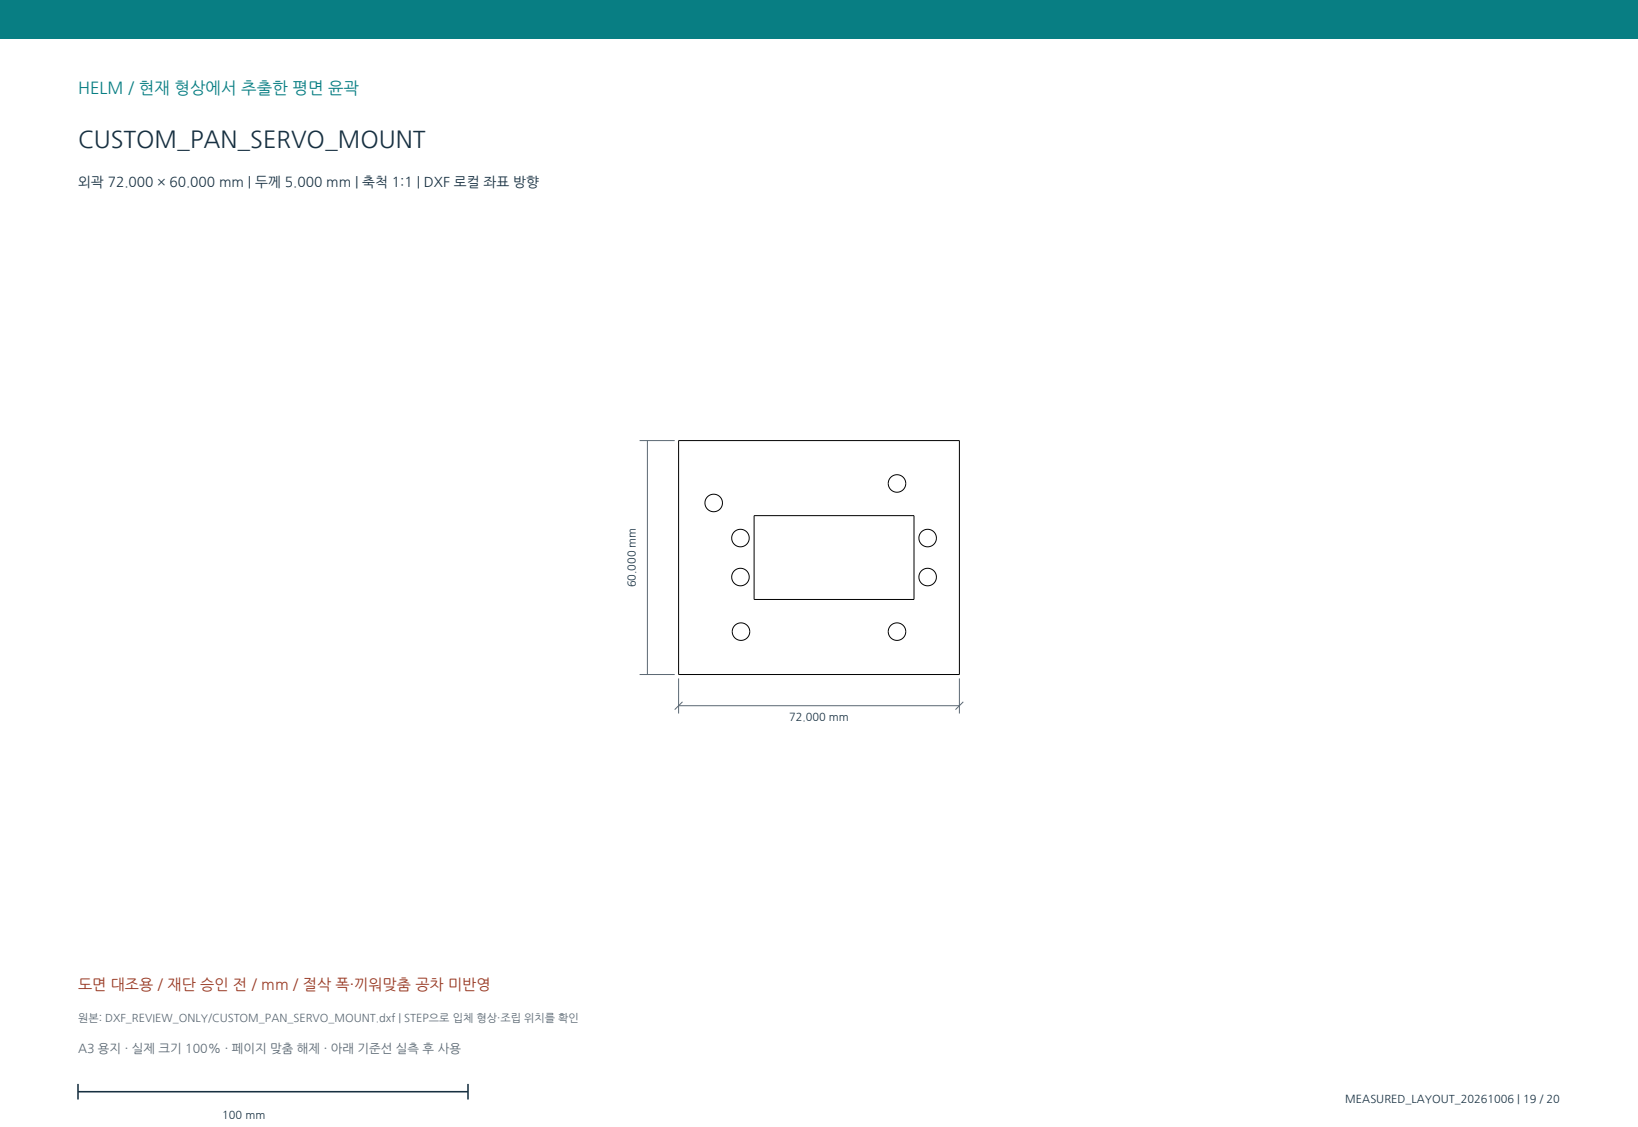
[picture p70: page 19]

도면 대조용 / 재단 승인 전 / mm / 절삭 폭·끼워맞춤 공차 미반영

원본: DXF_REVIEW_ONLY/CUSTOM_PAN_SERVO_MOUNT.dxf | STEP으로 입체 형상·조립 위치를 확인

A3 용지 · 실제 크기 100% · 페이지 맞춤 해제 · 아래 기준선 실측 후 사용

# CUSTOM_TILT_SERVO_MOUNT

### 외곽 72.000 × 49.000 mm | 두께 5.000 mm | 축척 1:1 | DXF 로컬 좌표 방향

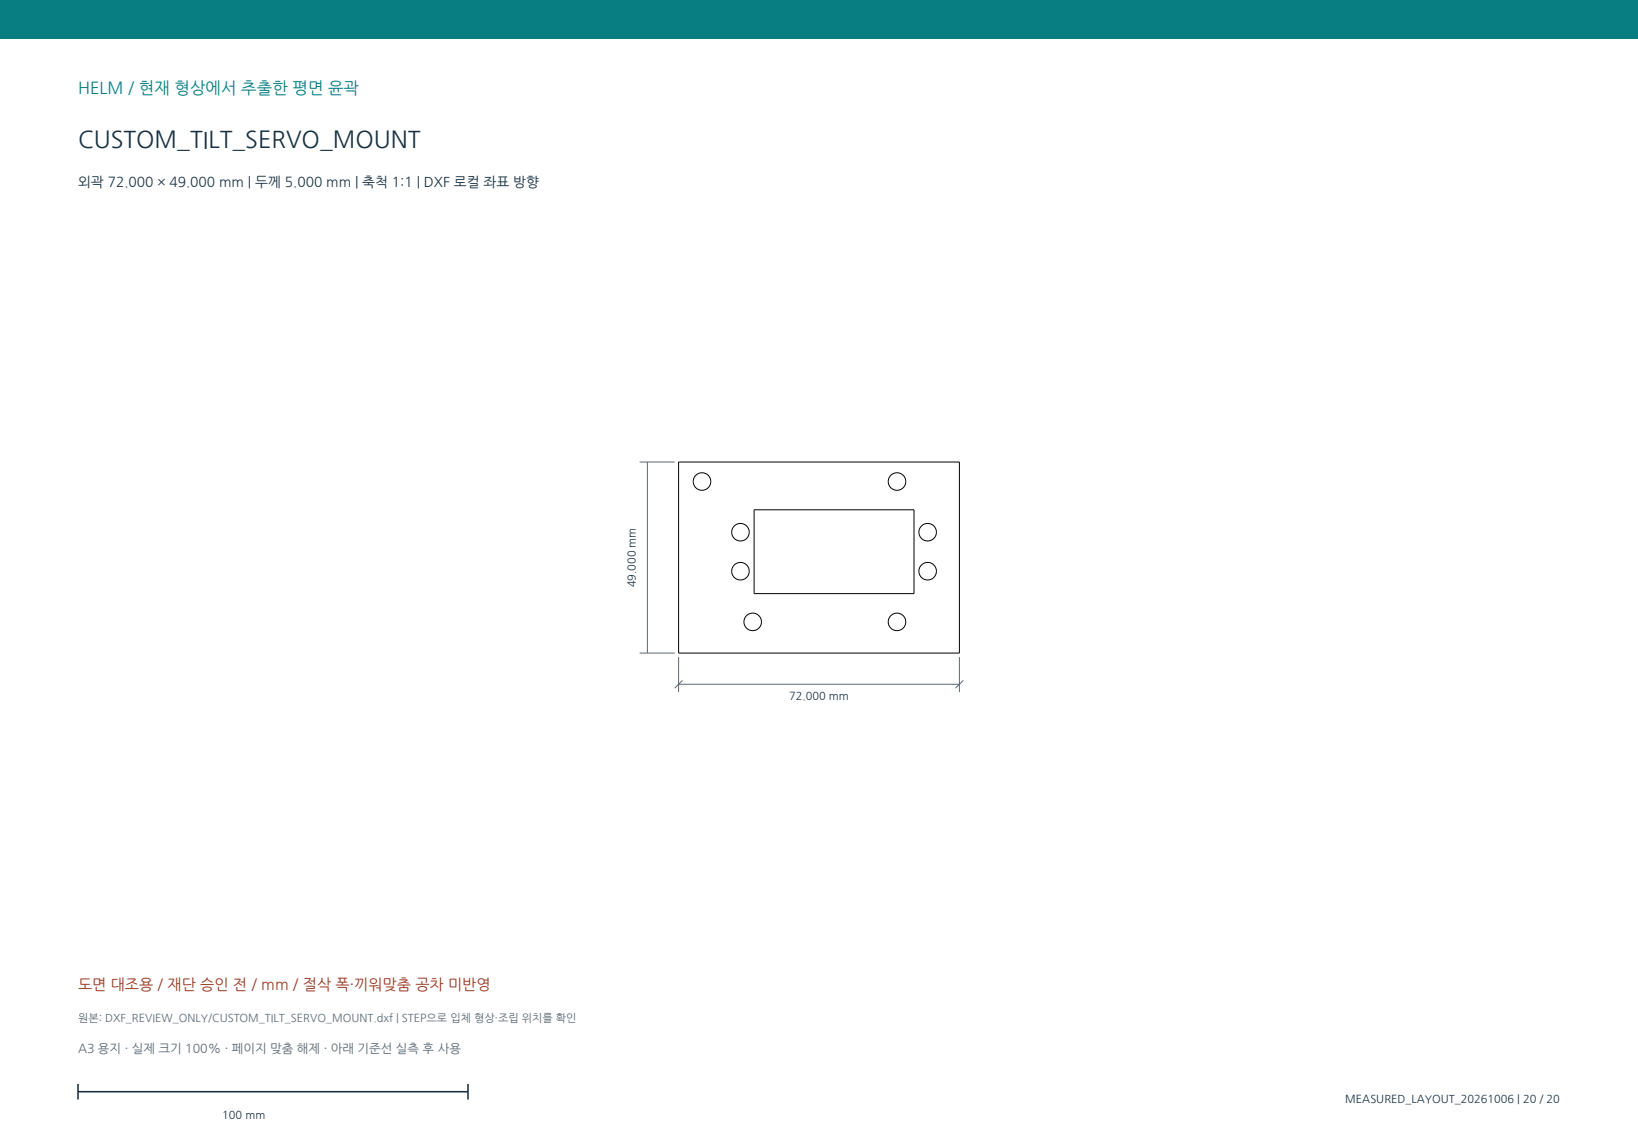
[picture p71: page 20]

도면 대조용 / 재단 승인 전 / mm / 절삭 폭·끼워맞춤 공차 미반영

원본: DXF_REVIEW_ONLY/CUSTOM_TILT_SERVO_MOUNT.dxf | STEP으로 입체 형상·조립 위치를 확인

A3 용지 · 실제 크기 100% · 페이지 맞춤 해제 · 아래 기준선 실측 후 사용

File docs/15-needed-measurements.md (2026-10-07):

# 필요한 확인과 현장 조정

## 필수·조건부 확인

| ID | 구매 ID | 부품 | 필요한 확인 | 완료 기준 |
|---|---|---|---|---|
| G1 | P2-R30 | SER0063 출력 혼 | 실제 사용할 혼의 홀 중심 간격·지름·두께·축에 끼운 체결면 높이 | 치수 스케치 또는 혼 STEP, 팬/틸트에 사용할 혼을 지정. 모터 몸체는 다시 잴 필요 없음 |
| G2 | P1-012 | 비상정지 스위치 장착부 | 실물 장착 지름·5T 판을 잡는 길이·뒤쪽 돌출 | 5T 자투리 끼움+너트 체결 시험과 후면 여유 확인. 맞으면 세부 외형 재측정 불필요 |
| G3 | P1-006 / P2-R51 | 섀시 기준 홀과 판 두께 | 실물 섀시 상부 기준 4홀에 1:1 종이를 대조; 실제 판 두께와 가조립 높이 | 네 점 모두 맞으면 새로 전부 측정할 필요 없음. 다르면 해당 홀 중심 좌표만 측정 |
| G4 | P1-014 | 범퍼 스위치와 복귀 기구 | 작동점·여유 이동·복귀 확인; 실제 스프링/가이드 보유 여부 | 간이 지그에서 네 방향을 눌러 작동과 복귀를 확인. 미보유 스프링 등을 가상 재고로 취급하지 않음 |
| C1 | P1-029 | 원형 로커 스위치 | 5T 자투리 Ø20 끼움·걸림턱·후면 34.2 깊이 | 자투리 합격 후 본판. 정밀 전 치수 측정 대신 끼움 시험 가능 |
| C2 | P2-R78 | MG995 금속 프레임 | 안쪽 폭·판 두께·축홀 피치와 지름·원형 지지부 치수 | 사용하지 않으면 측정 불필요. 사용 시 혼과 함께 대조 |
| C3 | P2-R54 / P2-R55 / P2-R53 / P2-R75 | 카메라 회전부 꺽쇠·체결품 | 소형 보유 확인 또는 중형 재배치; 회전 안쪽 돌출 높이·볼트/너트 실제 간격 | 혼 확정 후 배치 수정과 회전 검사. 고정된 판의 일반 꺽쇠는 현장 전사 가능 |

## 현장 조정

| 대상 | 방법 | 제한 |
|---|---|---|
| 고정 ㄱ자 꺽쇠·CP003·퓨즈박스 | 실물 놓기 → 덮개/공구 여유 확인 → 홀 중심 전사 → 가조립 | 기존 CAD의 가정 홀을 먼저 모두 뚫지 않습니다. |
| PCB·허브·USB 스피커 | 보드 모서리와 커넥터 여유를 맞춘 뒤 스페이서/벨크로 위치 선택 | 작은 칩 개별 측정 불필요. PCB 자체 홀을 임의로 넓히지 않습니다. |
| M3 스페이서·M4 전산볼트 | 실물 적층 높이와 너트·와셔에 맞춰 필요한 길이만 선택/최종 절단 | 회전부에서는 돌출 나사 끝과 공구 접근을 확인합니다. |
| EVA·벨크로·케이블 | 실제 압축 두께와 여유 길이로 현장 조정 | 방열구·배터리 단자·가동부를 덮거나 케이블을 팽팽하게 당기지 않습니다. |
| 미사용 재고·공구·개별 칩 | 전체 구매 목록에는 유지하되 로봇 CAD에 강제로 장착하지 않음 | 부스바와 MG995 프레임은 별도 선택 재고 형상입니다. |
| 배선·전원 통합 | 보유 배선·단자·퓨즈 규격으로 회로와 극성 대조 후 결선 | CP003 단자 크기를 고정홀로 오해하지 않습니다. CAD 배선 경로는 전기 검증이 아닙니다. |

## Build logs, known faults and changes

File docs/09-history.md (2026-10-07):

# 2026-10-06 실측 반영 / 2026-10-07 백업

93행·13개 치수 기록·3,888개 노드 매핑. 26개 형상 수정, 190개 구형·미구매·무효 형상 제외. [현재 내용](16-measured-layout.md). 제조 승인 보류를 유지합니다.

# 작업 이력

| 시점 | 실제 작업 | 해석 |
|---|---|---|
| V13 기존 기준 | 조립체·제작 부품·배선 참조 구성 | 기존 편집 자료를 이어받음 |
| 2026-09-29 V13-REISSUE | BREP 유지, STEP·130개 부품·54개 DXF·202쪽 PDF 재출력, 열화상 메타데이터 3개 정정 | 출력/파일 검증, 실물 승인 아님 |
| 2026-09-30 구매 기준 | 이전 CSV=1차, 이번 XLSX=2차 | 새 품목 전부 사용 강제하지 않음 |
| 2026-09-30 SER0063 | 모터·판·지지봉·높이 수정 | 혼/실물 체결품 미확정 |
| 같은 검토 | 보드/측판과 새 지지봉 간섭, 회전 중 LiDAR 받침 간섭 수정 | 검사 범위와 잔여 간섭 기록 |
| 2026-09-30 전달 | 검토 ZIP·6쪽 변경 안내 저장 | 최종 재단본 아님 |
| 2026-10-01 GitHub | 문서·원본·구매 행·코드·검증·기록 양식 정리 | 실물 제작/주행 결과는 제공되지 않음 |

[과거 V13 기록](../history/v13-reissue-20260929/) · [SER0063 전달 기록](../history/ser0063-review-20260930/DELIVERY_README_KO.md)

사용자 결정: 보유 부품 기준, 부품 불일치 시 교체, 추가품 전체 사용 불필요, 첨부 SER0063는 모터 CAD. 혼·회로·시험 결과를 임의로 완료 처리하지 않습니다.

2026-10-01 구매품 반영: C715 2280, CP003 외곽, 전원판 홀·홈 수정, 열화상 CAD 대조·PH2.0 정정, ADC 가정 제거. 4,078개 노드·128 STEP·20 DXF·6쪽 안내·20쪽 윤곽. 임시 공간 정리 뒤 입력 해시를 맞춰 재생성했고 변경부·9자세·출력 파일을 다시 검사했습니다.

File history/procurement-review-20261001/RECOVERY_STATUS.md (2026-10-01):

# 구매품 반영본 복원 기록

2026-10-01: 업로드 전 임시 작업공간 자동 정리로 로컬 수정본이 사라져, 보존된 V13/SER0063 아카이브와 대화의 치수·검사 기록으로 재생성 중입니다. 이 체크포인트는 완성 CAD가 아닙니다.

목표: C715 512GB의 실제 2280 슬롯 배치, CP003 100×45×33 mm 공간 모델, 전원 백플레이트의 구형 닫힌 홀 3개 제거와 하단 7×8 mm 홈 2개, 제조사 열화상 본체 보존·PH2.0 정정, 미구매 ADC 받침 및 관련 배선 제거.

보존된 SER0063 입력: 4,152 노드, manifest SHA-256 0b7b8cb640d072559c6d5957bcc3574d5be0e502dfbf6f83cc1efa5b37bced69. 구매품 반영 목표 4,078 노드.

SSD 카드 외곽 시작 X=22.7950001, Y=53.376875, PCB 상면 Z=273.323821523386 mm. 명목 PCB 80×22×0.8 mm, 전체 두께 2.5 mm. 끝단 기준 (102.7950001,64.376875,273.323821523386).

CP003 세계 좌표 경계 [65,10,155,165,43,200] mm. 구형 닫힌 홀 중심 XZ=(74,181),(164,152),(164,181), (74,152)는 기존 개구부 안이므로 그대로. 전원판 하단 Z=134.3898922198363, 홈 중심 X=125.969558604152 및 153.969558604152 mm.

앞선 검사 기록은 변경부 후보 29쌍에서 의도하지 않은 0.5 mm³ 초과 겹침 0건, M.2 접점의 의도된 명목 접촉 1쌍, 카메라 9자세에 기존 체결부 15쌍 잔류였습니다. 복원 후 결과를 다시 확인해야 합니다.

혼·MG995 브래킷·네이쳐툴 꺽쇠·CP003 고정부/단자 치수, 보유 체결품, 강도·전원·배선은 미확정입니다. 보유품만 사용하며 최종 제작 승인으로 표시하지 않습니다.

후속 상태: 4,152개 입력 해시가 원래 기록과 일치하도록 복원했습니다. 4,078개 최종 검토 형상·128 STEP·20 DXF·6쪽 안내·20쪽 윤곽을 재생성하고 변경부·9자세·파일 재읽기를 다시 확인했습니다. 현재 데이터의 수치·해시가 이전 미업로드 결과를 대체합니다.

## 최종 아카이브 재복원

추가 작업 공간 정리 후 GitHub 체크포인트와 보존 ZIP으로 재생성했다. 4,078개 노드의 메타데이터와 간섭 검증 결과는 체크포인트와 정확히 일치한다. 전체 STEP은 재내보내기 시각에 따라 해시가 바뀌므로 최신 FULL_STEP_READBACK.json과 아카이브 해시를 기준으로 한다. SSD 미리보기에서 가리는 지지판만 숨겨 명목 카드와 실제 소켓·끝단 지지부를 보이게 했다. CAD 형상은 바꾸지 않았다.

GitHub 연결에서 16 MiB 블롭 전송이 실패해 4 MiB 전송 성공을 확인한 뒤 최신 ZIP만 56개 조각으로 재분할했다. 전체 ZIP SHA-256은 `12390393ead32219a6b898b747dd1469170536a5e1e0bfa7ac7cbfdf60cd4690`으로 동일하며 이전 세 아카이브는 변경하지 않았다.

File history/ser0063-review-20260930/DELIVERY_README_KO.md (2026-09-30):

# HELM SER0063 교체 검토 패키지

**상태: 조립 검토용. 최종 재단·통전용으로 승인된 도면이 아닙니다.**

1차는 이전 CSV의 왼쪽 구매 목록 29품목, 2차는 이번 XLSX `2주차!A20:I83`의 64행을 기준으로 했습니다. 추가 구매품 전체를 CAD에 강제로 넣지 않았습니다. 비교견적의 예시·대안도 추가 재고로 세지 않았습니다.

## 먼저 열 파일

- `HELM_SER0063_CHANGE_GUIDE_KO.pdf`: 변경 내용, 종이 대조용 1:1 장착판 2종, 재단 전 확인 순서.
- `CAD/HELM_SER0063_FULL_REVIEW.step`: 전체 조립 검토 STEP. 단위 mm.
- `CAD/HELM_SER0063_CAMERA_REVIEW.step`: 변경 부품 중심의 카메라 검토 STEP. 전자부 데크도 포함합니다.
- `PART_STEP/`: 변경 또는 높이 이동된 제작 부품 17개. 모두 새로 잘라야 한다는 뜻이 아닙니다.
- `DXF_REVIEW_ONLY/`: 일정 두께 평판으로 추출 가능한 7개 윤곽. mm, 절삭 폭 보정 없음. 재단 확정 파일 아님.
- `DATA/`: 실제 구매 행, 변경 부품 목록, 간섭 검사와 재불러오기 결과.
- `OPEN_ISSUES_KO.md`: 남은 간섭의 한글 위치 설명, CAD 부품 이름, 필요한 실물 확인 목록.
- `SOURCE/`: 첨부 SER0063 원본 STEP과 수정·검증 스크립트.

## 실제 바뀐 내용

MG90S 2개를 사용자 제공 SER0063 STEP으로 교체했습니다. 모터 형상은 축척 변경 없이 강체 이동했습니다. 카메라 이동부를 24.38 mm 올리고 팬·틸트 장착판 및 오른쪽 지지판을 수정했습니다. M4 전산볼트 지지점과 길이는 새 모터와 기존 부품 간섭을 확인해 조정했습니다. 지지봉 검토 길이는 64 mm ×4, 38 mm ×4, 20 mm ×8입니다. 실제 체결품이 다르면 다시 확정해야 합니다.

이전 MG90S 혼·틸트 연결구와 서보 2개/C920의 기존 케이블 경로는 제거했습니다. 없는 혼을 임의로 만들어 체결 완료로 표시하지 않았습니다. 팬 축의 2 mm 혼 공간은 임시값입니다.

## 검증과 한계

- 새 모터 몸체 2개와 장착판 2개: 주변 강체와 정지 상태 교차 검사.
- 새 모터·체결부 후보 136쌍: 0.5 mm³ 초과 겹침 0건.
- 개별 부품 STEP 17개 및 카메라 STEP: 다시 읽어 형상 유효성 확인.
- 회전 9자세: 기존 카메라 체결부 등에서 자세별 6-10건의 겹침이 남음. 자세와 부품 이름은 `DATA/EXTENDED_VALIDATION.json`.
- 연속 운동, 없는 혼, 유연 케이블, 구조 강도, 전원 용량은 검증되지 않았습니다. 모델의 움직임 그룹과 임시 축을 이용한 검사입니다.
- 기존 CAD의 다른 가정부품·배선은 그대로 남아 있습니다. 전체 구매품만으로 조립 가능하다는 검증은 끝나지 않았습니다.

## 구매품 적용 판단

SER0063는 확정 교체했습니다. 포맥스 5T와 M4 전산볼트는 장착 검토에 사용했습니다. 보유 MG995/MG996 금속 브래킷은 실측 없이 호환을 단정하지 않았습니다. SZH-CP003 배전 단자대와 C715 SSD는 기존 모델과 다른 항목으로 후속 확인이 필요합니다. 전시 LED 패널과 데스크 스피커를 차체에 강제로 넣지 않았습니다. 혼합 체결 세트 등은 설명의 세트 수와 수량 열이 달라 실물 개수 확인이 필요합니다.

## 재단을 시작하기 전

동봉 혼의 위·옆 사진과 금속 브래킷의 위·옆 사진을 자와 함께 촬영하세요. 특히 혼의 구멍 중심 간격, 두께, 축에 끼운 높이, 브래킷의 내측 폭·구멍 간격이 필요합니다. 이를 반영하고 남은 간섭·강도를 해결한 뒤 재단 치수를 확정합니다. 현재 PDF의 1:1 판은 종이 맞춤용입니다. 구매 목록의 재료는 합판이 아니라 5T 포맥스입니다.

확정 뒤에는 판재에 부품 번호와 기준 모서리를 표시하고 시험 조각에서 절삭 폭·구멍을 확인합니다. 부재를 고정하고 보유 칼·톱·드릴로 가공하며, 절단면은 줄·사포로 마감합니다. 전체 판재 배치/수량 최적화는 이번 검토 범위에 포함되지 않았습니다.

## 출처와 재현

- 이전 CAD: `HELM_V13_CAD_DRAWINGS_FINAL_20260928.zip` (기존본은 유지).
- 1차 CSV: `1차-2차 부품 정리  - 1차-2차 부품 정리 (2).csv`.
- 2차 XLSX: `[일경험] 2기 재료비 신청서 (비교견적 포함)_임베디드X.xlsx`, `2주차` 시트 구매 행.
- 모터: `LIB_SER0063.zip / SER0063/3D/SER0063.stp`.
- 제조사: https://www.dfrobot.com/product-2787.html (2026-09-30 확인).

수정 스크립트는 원래 V13의 `HELM_V13_WORK` 캐시와 cadquery/OCP 환경을 전제로 합니다. ZIP 안의 STEP은 별도 생성 스크립트 없이 CAD 프로그램에서 열 수 있습니다. `SOURCE` 스크립트의 경로 설정은 재현 시 작업 폴더에 맞춰야 합니다.

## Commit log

2026-09-30 docs: consolidate HELM CAD, procurement and build preparation
    Preserve V13 and SER0063 review artifacts, source archives and verification records. Add Korean manufacturing preparation guides, archive restoration tools and an explicit list of unresolved design a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
    [APPROX_CAM_L_LEFT.step, APPROX_CAM_L_RIGHT.step, BOM_DRAWING.csv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]
2026-10-01 chore(cad): checkpoint procurement recovery inputs and exact change parameters
2026-10-01 chore(cad): preserve recovered procurement revision source before export
2026-10-01 Checkpoint regenerated procurement CAD text assets (1/3; REVIEW ONLY)
    [APPROX_CAM_L_LEFT.step, APPROX_CAM_L_RIGHT.step, CUSTOM_5V_DISTRIBUTOR.dxf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]
2026-10-01 Checkpoint verified procurement CAD, evidence records and reconciled build documentation (REVIEW ONLY)
    [CUSTOM_PAN_ARM_RIGHT.step, CUSTOM_PAN_SERVO_MOUNT.step, CUSTOM_PAN_YOKE.step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]
2026-10-01 Preserve completed procurement assembly previews before archive recovery
2026-10-01 Back up HELM procurement CAD review and fabrication guidance
    Apply owned C715 SSD and CP003 envelope/backplane revisions; retain verified thermal geometry and remove unpurchased ADC assumptions.
    Includes the 4078-node assembly, editable BREP snapshot, 128 fabrication STEP files, 20 DXFs and 26 PDF pages. Changed-part validation passed; 15 existing camera interference pairs and measured mounting interfaces remain unresolved. REVIEW ONLY.
    ZIP SHA-256: 12390393ead32219a6b898b747dd1469170536a5e1e0bfa7ac7cbfdf60cd4690
2026-10-06 Preserve reproducible measured CAD revision source; fabrication holds retained
2026-10-07 Back up measured CAD geometry and verified delta restoration
2026-10-07 Finalize measured CAD records, drawings and fabrication holds
    Map all 93 purchase rows and 13 dimension records to the 3,888-node measured review. Preserve the editable CAD delta and baseline, align build and FlutterFlow guidance, and record critical pre-cut ch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
    Verify all five archive hashes, current evidence counts and the 640-file repository catalog. Manufacturing release remains false.
    [HELM_부품번호_실측적용표.xlsx, measurement-register.csv, parts-numbered.csv]
